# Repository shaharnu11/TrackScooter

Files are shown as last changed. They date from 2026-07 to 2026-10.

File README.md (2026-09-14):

# Apollo Track Pod — Articulated Split-Frame Suspension

Hub-motor scooter → tracked vehicle conversion. **This root is an index only — all working
files live in the per-revision folders. Every future change lands in the live revision below.**

## Live revision

**[`archive/rev012-inline-batteries/`](archive/rev012-inline-batteries/) — Rev 012, live.** The pod is
Rev 011 (below, unchanged). Rev 012 adds the scratch-built **narrow frame**: two 100×40×2 rails bolted
straight onto the rear pod's 60×6 green plates (4× M12), the two 400×110×80 batteries in line between
them, and a 6.5″ speaker firing up through the deck at each end. Bay 1226 clear, wheelbase 1706,
chassis ~21 kg. `render_mode="chassis"`; printable green-plate templates:
`rev012_green_plate_templates.pdf`.

**Pod — Rev 011** (source folder [`archive/rev011-uncut-11T-lowB/`](archive/rev011-uncut-11T-lowB/)):

No grinder: the hub rim stays factory Ø165×35, driven by a printed 11-tooth sprocket
(rib 18×16.5, wheel Ø198, cord Ø210, tooth marks every 56.6 mm on the rib). The defining
change is that the hub sits **20 mm lower** over the idler axle line (B = 150), which stops
the 1080 mm belt wasting length on its two diagonals:

| | value |
|---|---|
| Ground contact | **231.2 mm** (was 203.5 — +13.6 %) |
| Ground pressure @ ~130 kg | ~0.24 kg/cm² |
| Wheel travel | +30.7 / −29.2 mm at ±15° |
| Motion ratio | 0.4351 — the purchased springs' design point |
| Cut lengths | carrier 220 · trailing arm 184 · leading arm 166 (rear corners chamfered 10×10) |
| Guards | all PASS, zero warnings |

Folder contents: model (`apollo_track_pod_rev011.scad`), printable sprocket
(`sprocket_print.scad` + `stl/`), 2D wheel blueprint, plate cutting sheet + DXF, pod
blueprint, README, archive note.

(The first, wide box-frame Rev 012 draft stays in the Rev 011 folder as history.)

## Shared facts

Yonggu belt 1080 × 118 @ 60 pitch (pyramid-pair lugs, 22 mm centre gap) · idlers Ø108
(tread 20.27 rides *in* the lug gap) · M12 GB901 8.8 double-end stud axles + Ø15×12 sleeve
stacks (purchased) · shocks 150 mm / 100 kg-8.5 mm springs · no keel (the fork legs box the
carriers) · motor casing Ø123, hub fins 4.1 mm arching to the tunnel-floor underside.

## External documents

- **Shopping list (live, robot-maintained):** [Parts to Buy](https://docs.google.com/document/d/1putRc1Q8nmpfGutUm1MNZg5LL_oXczPzJIrjNoAym6Y/edit)
- **Drive-wheel explainer (to-scale):** https://claude.ai/code/artifact/2c1f69e1-ae04-409e-b36e-10e408f62c0e
- Older shopping docs / checklist sheet: archived in the same Drive.

## History (frozen — do not edit)

| Folder | What it was | Why superseded |
|---|---|---|
| `archive/rev010-cut-rim-10T-final/` | the grinder path: cut rim Ø149, 10T, contact 220.8 | retired 2026-08-10 — Rev 011 beats it on the factory rim |
| `archive/rev009-uncut-11T/` | Rev 011's parent: same wheel, B = 170, contact 203.5 | hub lowered in Rev 011 |
| `archive/rev008-cut-rim-9T/` | 9T max-torque wheel | excluded by the hub-fin measurement |
| `archive/rev007-cut-rim-10T/` · `rev005c/` · `rev003a/` | earlier eras | see each folder's `ARCHIVE-NOTE.txt` |

Each folder's `ARCHIVE-NOTE.txt` explains what it was and why it was superseded.

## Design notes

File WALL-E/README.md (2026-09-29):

# WALL-E

Two-track robot built on the two track pods in `../archive/`. Target: Midburn, Negev desert.

**Where we stopped:** [`PROGRESS.md`](PROGRESS.md) — read that before changing Brain, talk, or power.

- Pods: already built. This project does not modify them.
- Drive: skid steer. No steering fork.
- Control: radio remote. Autonomous safety layer on top.

## Guide

`WALLE-GUIDE.html` — whole project, one file, in build order. Open in a browser.

- 11 parts: how to use, what it is, plan, architecture, buying, frame and pods, build steps, power, firmware, safety, glossary.
- All drawings embedded. No external image files.
- PDF: open and print. One part per page break. Sheets are vector.

## Per-document pages

Every `.md` has an `.html` twin of the same name:

- `docs/00-plan.md` → [`docs/00-plan.html`](docs/00-plan.html)
- Also [`docs/BUILD.html`](docs/BUILD.html), [`docs/FRAME_AND_PODS.html`](docs/FRAME_AND_PODS.html), and the rest.
- Each page is self-contained, drawings included, and links to the others.

Guide and pages come from the same markdown, built by the same script. They cannot disagree.

## Folder

```
WALL-E/
  WALLE-GUIDE.html   whole project, one file. Generated
  build_guide.py     generates the guide and every document page
  docs/              X.md is source, X.html is generated
  cad/               model, pod interface, render script
  firmware/          Spine (Teensy 4.0), Face (ESP32-S3)
  brain/             Brain (Dell XPS 15), Python
  build/             scratch drawings. Not committed. Deletable
```

## Rebuild

```sh
cd WALL-E
cad/render_all.sh       # pod check, guards, redraw, then rebuild the guide
python3 build_guide.py  # guide and document pages only
```

`cad/render_all.sh` stops on a failed pod check or a failed guard. A clean run is proof the change is consistent.

## Pod rule

- The pods are built. **No new hole goes into a built pod.**
- Their 31 numbers exist in one file: `cad/pod_interface.scad`.
- `cad/check_pod_interface.scad` compares that file against the newest pod revision in `../archive/`.
- `cad/pod_latest.sh` selects that revision. Nothing is pinned by hand.
- MISMATCH: stop. Every dimension downstream is wrong.

2026-09-29: 31/31 agree with `rev013-double-shear` (7 new: the U braces the frame hangs from).

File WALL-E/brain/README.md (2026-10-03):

# Brain

WALL-E's laptop side: talking (mic, camera, brain, voice) and the robot
control loop. Same code on the Mac and the Windows XPS.

## Start

| What | Mac | Windows (XPS) |
|---|---|---|
| Talk, English | double-click `mac/english/start_walle.command` | double-click `windows\start_walle.bat` |
| Talk, Hebrew | double-click `mac/hebrew/start_walle.command` | `legacy\talk_hebrew.py` (old Hebrew talker) |
| Setup | [`mac/README.md`](mac/README.md) | [`windows/README.md`](windows/README.md) |

Or `.venv/bin/python talk.py --help` for every option (`--lang`, `--brain`,
`--personality`, `--mind cloud`, `--type`, ...).

## Folders

```
brain/
  talk.py            start talking (calls walle/talker.py)
  robot.py           the robot control loop (20 Hz: Spine, eyes, behaviour)
  walle/             all the code
    talker.py        the talk loops: listen, answer, barge-in, owner/visitor
    paths.py         every data folder, in one place
    lang.py          English / Hebrew lines: t(en, he)
    voice/           speech.py (Whisper + Kokoro), listen.py (speech detector),
                     echo.py (echo cancelling), loud_listen.py, util.py
    mind/            chat.py (local / cloud brains, eyes), brains.py (--brain list),
                     llama.py (llama-server), rules.py, sleeper.py
    eyes/            camera.py (faces, lips), talk_cam.py (camera window)
    people/          owner.py (Shahar's face), persons.py (people who said yes)
    modes/           management.py, personality_editor.py, tools.py (owner tools)
    music/           player.py (music folder), spotify.py
    robot/           perception.py, behavior.py, speaker_lock.py, spine_link.py, face_link.py
  rules/             how he must behave (every personality); the owner changes them in management mode
  personalities/     english/<name>/, hebrew/<name>/: who he is
  scripts/           download_models.py, spotify_sync.py, lips_test.py,
                     personality_from_video.py, download_hebrew_windows.py
  tests/             test_safety.py, test_speaker_lock.py
  experiments/       try-outs: debug_live.py, try_hebrew_voice.py, try_speaker_lock.py
  legacy/            the old Windows Hebrew talker (talk_hebrew.py, hebrew_voice.py)
  requirements/      voice.txt (talking), hebrew.txt (old Hebrew), robot.txt (control loop)
  mac/  windows/     start scripts and setup notes per computer
  models/ owner/ persons/ spotify/ music/    data (models and persons/ not in git)
```

Run every script from `brain/` (`.venv/bin/python scripts/lips_test.py`);
the owner's face enroll is `.venv/bin/python -m walle.people.owner enroll`.

## Robot control loop

XPS 15 9510. Python. Camera, personality, sounds, optional local LLM. **No internet.** Allowed to be slow and to crash. Radio is on the Spine.

Closed on the upper tray, spacers. PD 65 W+ and 12 V pack on the lower deck. USB hub on the tray (12 V rail): ELP camera, LiDAR, Teensy, Face. Speaker boxes off → tray out.

```bash
python3 -m venv .venv && . .venv/bin/activate
pip install -r requirements/robot.txt
python3 robot.py --spine /dev/ttyACM0 --face /dev/ttyUSB0 /dev/ttyUSB1
python3 tests/test_safety.py
```

Windows: `COM` ports. Sensor libs commented until hardware exists.

## Load-bearing

1. **Heartbeat is the command**, from the control loop, not a side thread. Loop stall → beat stall. Zero command is still a beat.
2. **AI never emits a motor number.** Actions: `idle` · `look_at` · `greet` · `retreat` · `nudge_forward` · `follow` · `play_sound`. `motion_for()` maps them. Cap 30 % (`tests/test_safety.py`).
3. **Stale ≠ clear.** Every reading has a time. Missing IMU blocks motion. Missing bumper halves speed.

Sensor threads write one slot. No queues.

## Still empty

IMU, LiDAR, sounds in the control loop.

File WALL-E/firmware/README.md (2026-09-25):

# Firmware

Two boards, two jobs, and a hard line between them.

| Folder | Board | Job | May it move the robot? |
|---|---|---|---|
| `spine/` | Teensy 4.0 | Motor commands, every safety rule, the watchdog | **Yes. Only this board.** |
| `face/` | ESP32-S3 × 2 | Eye animation. No servos | No |

The Brain (the Dell XPS 15) lives in `../brain/` and is Python, not firmware.

---

## The Spine

**Board:** Teensy 4.0. **Library:** `Wire` only — it ships with Teensyduino.

Build with the Arduino IDE (install Teensyduino first) or PlatformIO. Select
Teensy 4.0 and upload. There is nothing to configure at build time — every
tunable number is in `spine/config.h`.

> No data bus. Analogue throttle. `FlexCAN_T4` is gone.

### What it does

One loop at 1 kHz. Every pass it rebuilds the motor commands from scratch using
the fixed rule order in `../docs/01-architecture.md` section 3. The rules are in
`arbitrate()` in the same order as the document, with the rule numbers in the
comments, so the two can be checked against each other.

### How it drives a scooter controller

A scooter controller takes a **throttle voltage** and tells you nothing back.
So the Spine does all of this itself:

| What | How |
|---|---|
| Speed | MCP4725 DAC per side, through a level shifter (the Teensy is **not** 5 V tolerant) |
| Direction | a separate opto-isolated **reverse** line per side |
| Stopping hard | an opto-isolated **e-brake** line per side, the same input the E-stop uses |
| Pack voltage (rules 5, 11) | a resistor divider per pack into an analogue pin |
| Motor temperature (rule 9) | each hub motor's **own thermistor** |
| Is the track alive? (rule 4) | counting that motor's **hall edges** |
| Motor current | ACS758 per pack — telemetry only, no rule depends on it |

### Pins

| Pin | Use |
|---|---|
| 0, 1 | Serial1 — iBus from the RC receiver |
| 2 | Arm output → contactor coil MOSFET. LOW = contactors drop |
| 3 | E-stop sense, active LOW |
| 4 | ToF ring reset |
| **5** | **Watchdog kick — see below** |
| 6, 7 | Reverse line, left / right |
| 8, 9 | E-brake line, left / right |
| 10, 11 | Hall input, left / right |
| 13 | On-board LED heartbeat |
| 18, 19 | I2C — the two DACs and the ToF multiplexer |
| A0, A1 | Pack voltage divider, left / right |
| A2, A3 | ACS758 current, left / right |
| A6, A7 | Motor thermistor, left / right |

### The watchdog is the most important wire on the robot

**A scooter controller never releases the motor on its own**, and the DAC holds
its last voltage forever. So if this board
crashes mid-drive, the robot keeps going at whatever throttle it had.

The only thing that stops it is the hardware watchdog: pin 5 square-waves while
the firmware is healthy, holding a **normally-closed** relay open. Stop the
pulses and the relay falls closed and shorts both throttle lines to ground.
Nothing in software has to work for that to happen.

`wdt_kick()` refuses to kick when the last DAC write failed. That is not a bug
and it is not optional — see the gotchas at the bottom.

### Before you flash it to a robot that can move

Read the five rules at the top of `spine/spine.ino`. The short version: no
dynamic memory, nothing that blocks, nothing with unbounded runtime, every new
failure path ramps to zero, and features belong on the Brain.

Then **measure your own throttle** and put the numbers in `config.h`:
`THROTTLE_REST_V` and `THROTTLE_FULL_V`. Read the scooter throttle's signal
wire at rest and at full with a multimeter. The defaults (0.80 V and 4.20 V)
are typical, not yours. Get them wrong and the robot either creeps when it
should be stopped, or never reaches full speed.

Calibrate `VOLT_SCALE_L` and `VOLT_SCALE_R` the same way: multimeter on the
pack, compare with the telemetry line, correct until they agree. Rule 11
divides by that number.

### Still to do

`tof_poll()` is empty. The bumper ring is not implemented yet.

This is deliberately failing in the safe direction: with no valid sensor
readings, `bumper_scale()` returns 0.5 and halves the speed. **Do not make it
return 1.0 to get full speed for a test.** That silently switches off the veto,
and it is exactly the kind of temporary change that stays in.

### Testing it without a robot

The Brain link is plain text, so you can drive the board from a serial
terminal at 115200:

```
C 0.2 0.0 1
```

means "20 % forward, no turn, sequence 1". Send one every 50 ms or the
watchdog will stop obeying you, which is itself a good first test. The board
prints a status line 20 times a second, including why it is not moving:

```
S 12345 manual running duty 0.200 0.200 v 49.8 49.6 t 31 30 i 2.1 2.0 hall 8123 8110 rc 1 brain 1 dac 1
```

`dac 1` means this board still controls the throttle. If it ever reads `0`, the
hardware watchdog should already have stopped the robot.

The tests that matter for this firmware are in `../docs/03-safety-log.md`:
**8** (throttle wire pulled — both tracks must stop), **15** (Spine unpowered),
**16** (Teensy alive but I2C dead), and **17** (reverse line glitch).

---

## The Face

**Board:** ESP32-S3, two of them, one per eye. **Libraries:** LovyanGFX.

### Same binary on both boards

Tie `PIN_EYE_SELECT` to ground on the left board and leave it floating on the
right. The firmware works out which eye it is at boot. There is only ever one
binary to keep track of, and swapping in a spare board in the field needs no
laptop.

### Why two boards and not one

The 480×480 round panels are QSPI and need real bandwidth. One ESP32-S3 can
*probably* drive two, and would then tear the moment you add anything else.
Two boards at 12 dollars each removes the risk and means one eye keeps working
if the other board dies. `../docs/05-bom.md` section 4.

The two are kept in step by a single wire: the left board pulses it, the right
board starts its frame on the pulse. If that wire breaks, each eye runs on its
own clock and the only symptom is that the blinks drift apart slightly.

### Still to do

`face/panel_cfg.h` is a placeholder. The QSPI panel's init sequence and pin
mapping have to be copied from the vendor's example for the exact module you
buy — it is the one part of this project that cannot be worked out from first
principles.

Everything else runs without it. You can develop and test the whole animation
over the serial link with no screen attached, which is worth doing because the
animation is the hard part.

### Testing it

Three commands, typed by hand at 115200:

```
GAZE -20 5
MOOD curious
BLINK
```

Moods: `idle`, `curious`, `happy`, `sad`, `alarm`, `sleepy`.

If the link goes quiet for 1.5 seconds the eyes fall back to an idle
behaviour — drifting around, blinking now and then. That is on purpose: a
crashed Brain should leave a robot that looks bored, not one that looks
broken. Frozen eyes read as "switched off" to everyone watching.

---

## The three details in here that are easy to get wrong

**The slew limiter's direction.** In `spine.ino`, `slew1()` treats "up" as away
from zero and "down" as towards zero. Swap them and stopping becomes slower
than starting, which is the wrong way round and would not be obvious from
watching the robot drive.

**`wdt_kick()` must stay gated on `output_ok`.** It looks like a bug — the
board is alive, so why not kick the watchdog? Because the watchdog's job is to
stop the robot when the **throttle** is out of control, not when the CPU is.
A Teensy that is running fine but has lost the I2C bus to a DAC would otherwise
keep kicking happily while the throttle stayed stuck at its last value. That
blind spot is closed by refusing to kick. Safety log test 16.

**The reverse line is never flipped while the wheel is turning.** `side_out()`
commands zero and waits for the halls to fall silent first. Scooter controllers
commonly refuse to change direction under motion, and some are damaged by being
asked. Removing that interlock would make direction changes feel snappier on
the bench and would eventually break a controller. Safety log test 17.

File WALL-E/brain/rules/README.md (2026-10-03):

# WALL-E's rules

How he must behave, in every personality. Read at start-up and added to his
instructions **after** the personality, which is told: if anything in it
conflicts with these rules, the rules win.

- The owner changes them by voice in management mode ("answers can be up to
  three sentences"): read back, saved on "yes", the old file in `history/`.
  Or by hand.
- These are soft rules, instructions to the brain: it almost always follows
  them. The hard rules live only in code and cannot be changed by voice: sentence limit, filters
  (walle/mind/chat.py), owner/visitor checks and tools (walle/talker.py,
  walle/modes/), consent (walle/people/persons.py).
- `<!-- comments -->` and `#` headings are not sent to the brain.

| File | When |
|---|---|
| always.md | always |
| english.md / hebrew.md | by --lang |
| eyes_picture.md | the brain sees camera pictures (Qwen3-VL) |
| eyes_described.md | the brain gets the picture as words (Hebrew: DictaLM + eyes) |
| eyes_none.md | no camera pictures |

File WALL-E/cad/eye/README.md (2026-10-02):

# WALL-E eyes — steel tube + printed cartridge

Decided with Shahar, 2026-10-01. One eye = one steel tube + one cartridge.

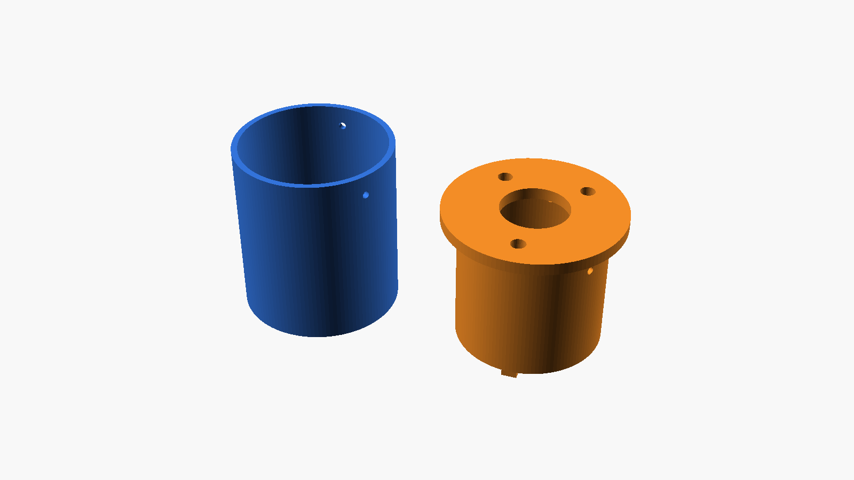
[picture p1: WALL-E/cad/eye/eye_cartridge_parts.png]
the 2 printed parts


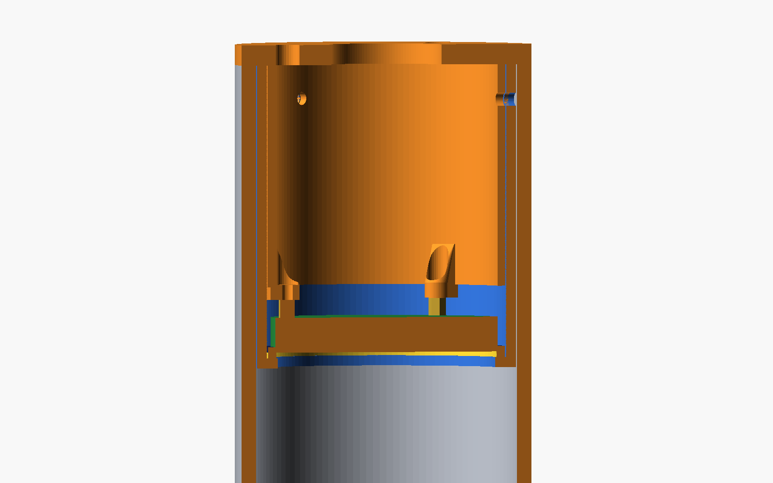
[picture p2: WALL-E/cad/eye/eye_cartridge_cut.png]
assembled, cut in half


## Decisions

- **Tube:** steel, **54 mm inside × 90 mm long** (owner's). Outside Ø: **measure**.
- **Screen + computer:** Waveshare **ESP32-S3-Touch-AMOLED-1.75**: round AMOLED
  466×466, 700 nits, ESP32-S3R8 on the back. Touch not used.
  - Bought: 2 × standard + 1 × **-G** (GPS version). The GPS board is one eye
    and the GPS. One standard board is the spare.
- **Sun shade:** glass front sits **33 mm deep**. Paint the inside of the tube
  **matte black**.
- **Mount:** 2 printed parts. The board screws onto part 2 with **3 × M2**
  into its own brass posts. The eye is built on the table, then slides into the
  tube. **3 × M3** from outside hold it.
- **Wires:** the USB-C is on the board edge, facing the tube wall: no room for a
  plug. Use the **header on the back** instead (see Wiring).
- **AMOLED burns in:** the eyes must always move a little, and turn off in sleep.

## Board numbers (Waveshare 3D model)

Measured from the glass front, along the axis:

| What | Size / depth |
|---|---|
| Glass | Ø48.96, 1.10 thick |
| Picture (visible) | Ø44.16 |
| Board | Ø46.0 |
| USB-C (edge, r 23.8) | ends 10.15 behind the glass |
| 3 brass posts, M2, Ø3.5 | tips 10.43 behind the glass; at (±13.75, 14.70) and (0, −20.50), header side up |
| Header (female, 8 pins) | ends 12.70 behind the glass |

## Parts per eye

| # | Part | Size | Source |
|---|---|---|---|
| 1 | Steel tube | 54 inside × 90 | owned |
| 2 | Matte black paint inside, front ~35 mm | steel primer + flat black | local |
| 3 | **Part 1** (`eye_part1.stl`): sleeve + front lip | outside 53.6, inside 49.5, lip hole 45, 60 long | print |
| 4 | Foam ring | outside 49, hole 45.5, ~1.5 mm | cut from closed-cell (EPDM) foam sheet |
| 5 | Eye board | Waveshare AMOLED 1.75 | bought |
| 6 | **Part 2** (`eye_part2.stl`): carrier tube + cap | outside 49.1, cap Ø = tube outside | print |
| 7 | 3 × **M2×6** screw | board posts → part 2 | local / AliExpress |
| 8 | 3 × **M3** self-tapping screw, ~8 mm | steel + part 1 + part 2 | local |
| 9 | **PG16** cable gland, black | in the cap, hole 22.8 | AliExpress |
| 10 | Silicone sealant | gland + the 3 screwdriver holes in the cap | local |
| 11 | 4 wires: Dupont male → header; 4-core shielded 24 AWG | VBUS, GND, TXD, RXD | AliExpress |
| GPS eye only | IPEX → SMA pigtail 20 cm, SMA extension 50 cm, QUESCAN antenna | antenna under the head top cover | bought |

## Print

- **PETG or ASA, black.** Not PLA (soft at ~55 °C; steel in the sun gets hotter).
- 4+ walls, 40 % infill (the screws go into it). No supports.
- Part 1: lip down. Part 2: the STL is already cap down.
- Print **3 sets** (2 eyes + 1 spare).
- Re-export after a change:
  ```
  openscad -D part=\"p1\" -o eye_part1.stl eye_cartridge.scad
  openscad -D part=\"p2\" -o eye_part2.stl eye_cartridge.scad
  ```

## Assembly (per eye)

1. GPS board only: unplug the small antenna (IPEX plug next to the USB-C, lift
   straight up), unscrew it. Plug the pigtail into the same socket.
2. Program the board once on the table, with a normal USB-C cable.
3. Plug the 4 wires into the header (male Dupont). Drop of hot glue on them.
4. Wires (and the pigtail) through the PG16 gland in the part 2 cap.
5. Board onto the 3 pads of part 2. **3 × M2×6** through the 3 screwdriver holes
   in the cap. Do not overtighten: the posts are small.
6. Stick the foam ring on the back of the part 1 lip.
7. Part 2 (with the board) into part 1, glass first, until the glass touches the foam.
8. Whole cartridge into the painted tube from the back, until the cap sits on the tube end.
9. Drill 3 × 3.2 mm through the steel at the 3 holes (7 mm from the end).
   Drive 3 × M3 self-tapping screws.
10. Tighten the gland. Seal the gland and the 3 screwdriver holes with silicone.

**Repair:** cut the silicone, remove 3 × M3, pull the cartridge out.

## Wiring

Header on the back: `IO18 · IO17 · IO16 · RXD · TXD · 3V3 · GND · VBUS`

| Eye pin | Goes to |
|---|---|
| VBUS | +5 V from the RCNUN 12→5 V converter |
| GND | GND (converter and CP2102) |
| TXD | CP2102 **RXD** |
| RXD | CP2102 **TXD** |

- The CP2102 plugs into the USB hub. Leave its +5V and 3V3 pins empty.
- GPS board: IO17 / IO18 belong to the GPS. Do not use them. The eye firmware
  forwards the GPS data on TXD/RXD.

## Files

| File | What |
|---|---|
| `eye_cartridge.scad` | the 2 parts. `part = "p1" / "p2" / "all" / "cut"` |
| `eye_part1.stl`, `eye_part2.stl` | ready to print |
| `eye_cartridge_parts.png` | the 2 parts |
| `eye_cartridge_cut.png` | assembled, cut in half |

## Still open

- Tube **outside Ø** → set `tube_od` (now 60, a guess) and re-export part 2.
  It only changes the cap's outer edge. Part 2 works as it is.
- Check the real board when it arrives (post positions, header height), before
  printing all 3 sets. Print 1 set first.
- Firmware: `firmware/face` is written for the old 2.1" screen. The new board uses
  a CO5300 driver (QSPI). Start from Waveshare's example code for this board.
- `cad/walle_frame.scad` and `docs/02-overview.md` still describe the old eye
  (Ø99 barrel, 60 mm recess, acrylic dome).

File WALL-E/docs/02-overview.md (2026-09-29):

# 02 — What this robot is

Two-track robot on the pods in `../archive/`. Midburn, Negev. Pods are built. This project does not modify them.

- Pods **side by side**. Skid steer. No steering fork.
- Box on top: batteries, three computers, two speakers.
- Rigid head. Two screens as eyes.

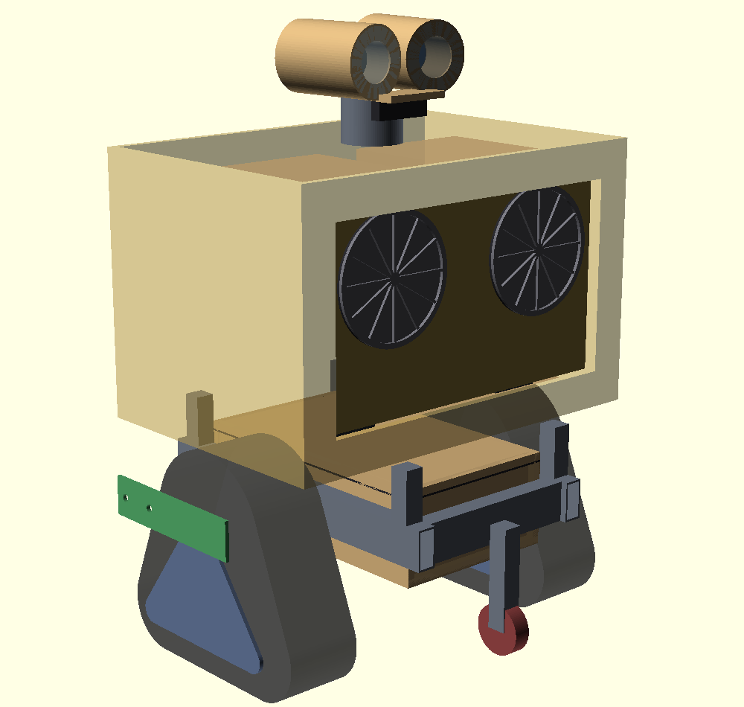
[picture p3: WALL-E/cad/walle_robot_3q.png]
The robot, three quarter view


## Control

- A person drives with a radio. **Not self-driving.**
- Safety: sensors veto obstacles, including against the stick.
- Personality: camera finds faces, eyes follow, body turns (head is rigid), sounds play.

## Three computers

| Name | Board | Job | Timing |
|---|---|---|---|
| Brain | XPS 15 9510 (owned) | Camera, local LLM, sounds | 0.1–3 s OK |
| Spine | Teensy 4.0 | Radio, motors, stop rules | 1 kHz |
| Face | ESP32-S3 × 2 | Two eye screens. No servos | 30 Hz |

- No internet. Radio and E-stop into the Spine.
- Brain crash: eyes and sound die. Driver keeps control.

## Numbers

Body narrower than the tracks on purpose.

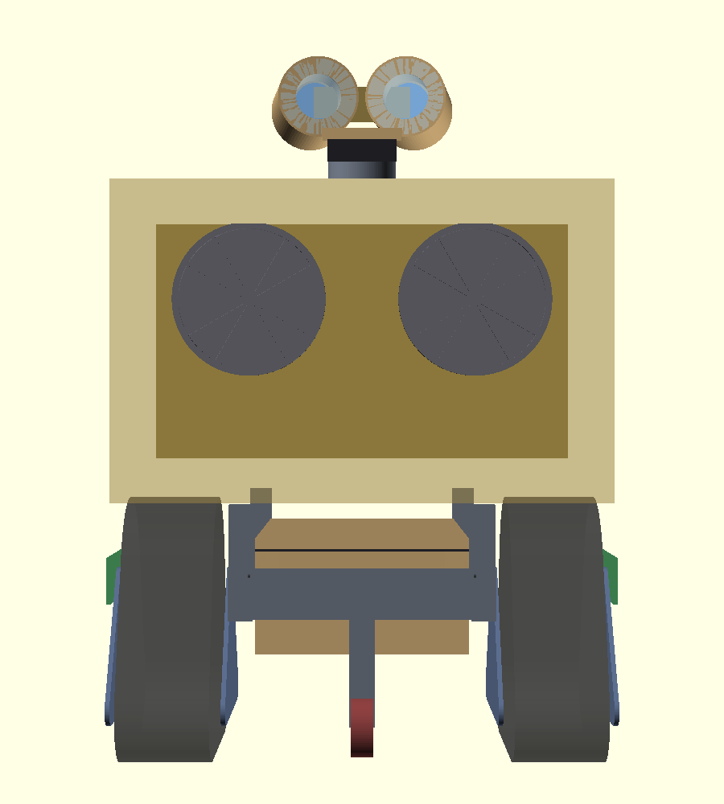
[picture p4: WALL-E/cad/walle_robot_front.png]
From the front


| | |
|---|---|
| Width | 677 mm (pod centres 500) |
| Height | 1003 mm to barrel tops |
| Body | 430 × 640 × 400, floor 428 mm |
| Rails | 60×30×3, 550 long, 251 mm clear |
| Lowest point | 150 mm (box floor) |
| Mass | 94.9 kg — pods/packs/electronics still guesses |
| CoM | 355.5 mm up, 4.5 mm forward |
| Tips forward | 17.4° (back 18.7°) |
| Castor catches | 12.3° — **5.1°** margin |
| Ground pressure | 0.174 kg/cm² |

The frame hangs from the pods' U braces. Pod off: 1 × M12 + 4 × M10 per side. Weigh a pod and a pack before trusting 17.4°.

## Model results

1. **No electronics in the frame.** 8 mm above packs, 24 mm between. Two floors in the body. 12 V pack 181 × 167 × 77 mm on the lower deck (not the 400 × 110 × 80 mm traction case). Upper: 315 × 360 mm tray for closed XPS + USB hub. Speaker boxes off, then tray out.

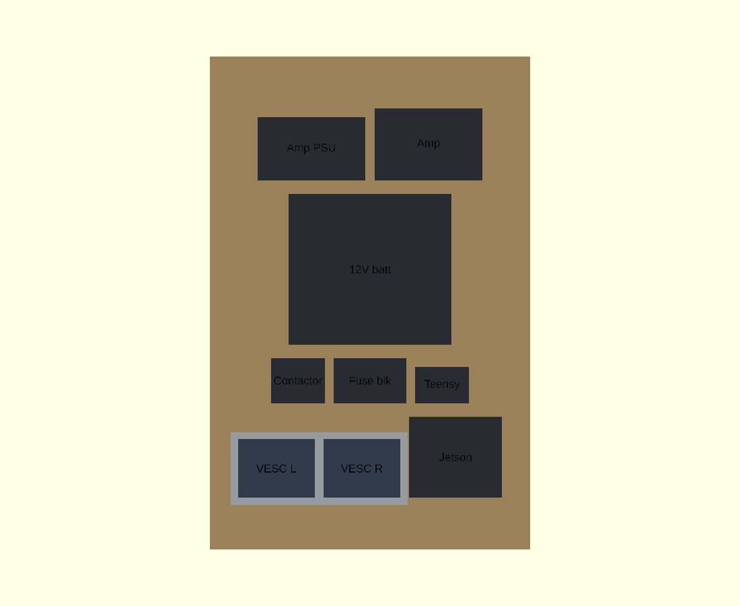
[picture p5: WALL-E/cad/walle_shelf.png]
The electronics shelf, labelled


2. **Body floor clears the U brace tabs** (413 mm + M10 heads), not the belt crown (327 mm) or the frame (252 mm). Four 176 mm risers.

3. **Battery box closed.** Six panels, gasket, plugs, vent. Daily charge in place. Packs still lift out (L17).

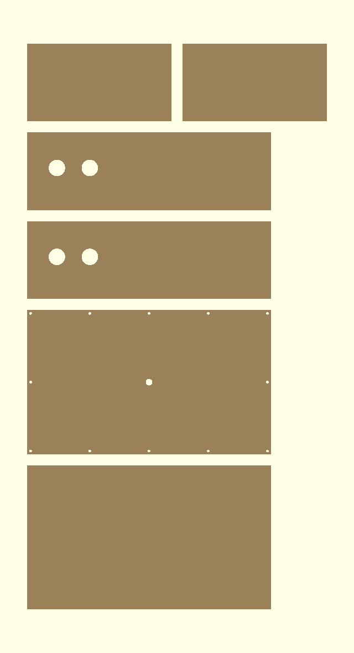
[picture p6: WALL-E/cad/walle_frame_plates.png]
The plywood cutting layout


4. **Chest is a 12 mm plate**, set back 20 mm. Speaker baffle.

## Speakers

- 2 × 6.5 inch, 330 mm apart, 613 mm up. On the chest edges. 140 mm between rims.
- 7 inch LCD, 107 × 183 mm, **portrait**, between them. HDMI from the XPS. Glass window 90 × 160. Bezel on the chest, not through the speaker boxes.
- 7.5 L sealed box each. Bolt on. Shade 54 % of the shelf.
- 6.8 kg, both forward. Castor margin now 5.1° (the U-brace mount lifted the body). Weigh before adding high/forward mass.

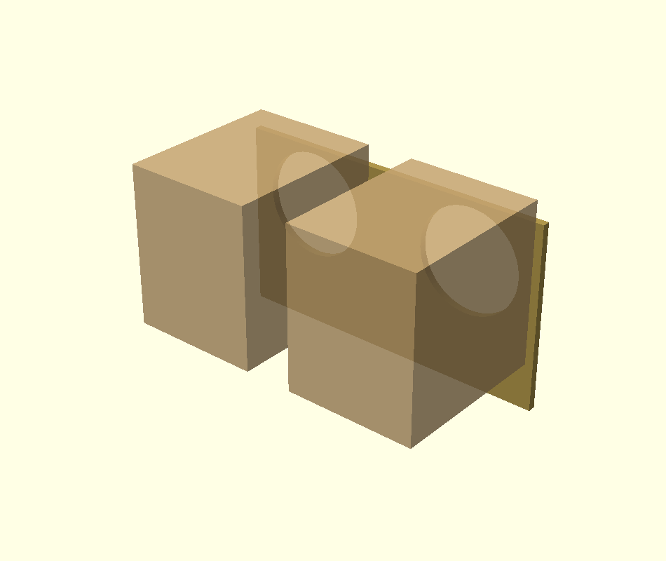
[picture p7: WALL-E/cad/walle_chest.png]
The chest panel and the two sealed enclosures, from behind


## Head

- Barrels Ø105, 128 mm apart, toe 6°.
- 2.1 inch screens, 60 mm recess, clear dome. Shade above 49° sun. Midday 75–80°.

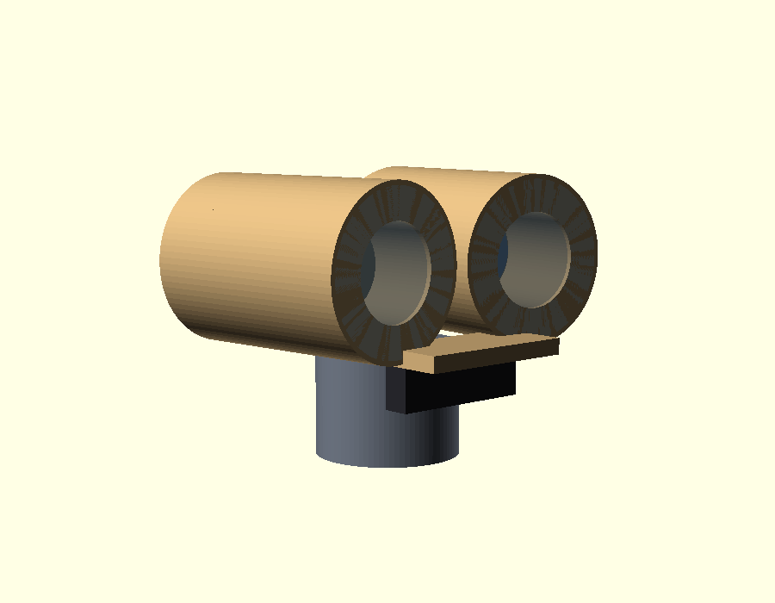
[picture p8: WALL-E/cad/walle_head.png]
The head, with the two eye barrels


Camera under the brow: ELP cube 42 × 42 × 36 mm, 86°.

## Built pods (rev013)

| | |
|---|---|
| Mounting width | **177 mm** over carriers (plates 165 mm) |
| Contact | 231 × 118 mm |
| Pod | 363 × 327 × 177 mm |
| Band | 60 mm, 197–257 mm up |
| Travel | +30.7 / −29.2 mm |

`../archive/rev013-double-shear/`. Tape-measure before welding.

## Open

1. D4 — pack Ah and BMS. Equal traction packs.
2. D3 — carry a person? Midburn rules before weld.
3. D6 — anti-tip. 231 mm is the whole footprint.

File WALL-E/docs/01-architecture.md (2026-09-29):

# 01 — Architecture

Three boards. The rules that decide who may move the robot.

## 1. Why three boards

| Job | Must react in | If late |
|---|---|---|
| Stop the motors | 1 ms | Someone gets hurt |
| Animate the eyes | 30 ms | Face looks broken |
| Read a camera frame | 100 ms | Nobody notices |
| Pick a line of speech | 3 s | Fine |

Linux can pause for seconds. A 200 kg machine must not. Motor commands live on a board with **no OS**.

## 2. Layout

```
RADIO ──2.4 GHz──► RC RECEIVER ──iBus──► SPINE (Teensy 4.0)
                                         ▲
LiDAR, ELP cam, GPS, mic ──► BRAIN (XPS) ┤ USB 20 Hz heartbeat
                         local, no net   │ HDMI ──────────► CHEST 7 inch LCD (portrait)
                         USB serial ─────► FACE (ESP32-S3 × 2, screens, no servos)

ToF ring ──► SPINE ──I2C──► 2× MCP4725 DAC ──opto──► 2× scooter controller ──► hub motors
E-stop  ──► SPINE           hardware watchdog shorts both throttles if kicks stop
```

- Radio and bumpers wire into the **Spine**, not the Brain.
- Brain crash costs eyes and sound. Driver keeps the sticks.

## 3. Spine loop (1 kHz)

Higher number loses. Every pass rebuilds motor commands from scratch.

| # | Check | If it fails |
|---|---|---|
| 1 | E-stop closed? | Motors dead. Physical. No override |
| 2 | Arm switch ON? | Send zero |
| 3 | Radio frame in last 100 ms? | Ramp to zero |
| 4 | Each track turning as commanded? (hall edges) | Ramp **both** to zero |
| 5 | Both pack voltages above the floor? (dividers) | Ramp **both** to zero |
| 6 | Mode switch | MANUAL = sticks. ASSIST = Brain may request |
| 7 | ASSIST only: Brain heartbeat in last 100 ms? | Ramp to zero, fall to MANUAL |
| 8 | Bumper close in the direction of travel? | Scale down or to zero. Veto only |
| 9 | Motor too hot? (hub thermistor) | Scale both down |
| 10 | Slew limit | Smooth ramp |
| 11 | Scale each side by its own pack voltage | Straight drive as packs drift |
| 12 | Write DACs. Kick watchdog | Stop kicking if a DAC write fails |

Every failure stops the robot. Nothing speeds it up or ignores the driver.

Controllers report **nothing**. So:

- Rule 4 = hall edges. Commanded to move, halls still: track is dead.
- Rules 5 and 11 = resistor divider per pack.
- Rule 9 = motor’s own thermistor.

A scooter controller has **no command timeout**. A DAC **holds its last voltage**. If the Teensy dies while packs are alive, only the **hardware watchdog** (NC relay shorts throttle to ground) stops the robot. Safety log tests 15 and 16.

## 3b. One pack per pod

Positives never meet. Negatives bonded at **one** point, including the 12 V pack negative. Do not fuse the bond.

**Trap 1 — crooked drive.** Same duty on 50 V vs 44 V is a pull. Rule 11 scales by pack voltage.

**Trap 2 — one dead side pivots the robot.** BMS cut is the usual cause. Rules 4 and 5 stop **both** tracks.

**Trap 3 — floating ground.** Far-pack readings look real and are wrong. One bond, three negatives, two positives that never meet. Bond sized for 40 A. Not fused.

**D8.** Electronics: 12 V 20 Ah, 181 × 167 × 77 mm, on its side, lower deck. Traction packs equal (~17.5 Ah). Drive ~5.6 h. Electronics ~12 h.

| What dies | What stops the robot |
|---|---|
| Pack A | Coils lose 48 V. Both contactors open. Copper |
| 12 V pack | Teensy dies. Arm MOSFET opens the coil chain |
| Pack B | Only rule 4 (halls). Contactor B stays closed with no power behind it |
| Teensy crash, packs alive | Watchdog only |

Coils stay on pack A. Amp stays on 48→24 V off pack A. Do not move either onto 12 V.

## 4. Brain heartbeat

Brain sends speed, turn, and a counter every 50 ms.

- Last message < 100 ms: continue.
- Else: Brain dead. Ramp to zero in 0.5 s (do not slam — 231 mm footprint can tip). Ignore Brain until messages return for 1 s.

In MANUAL a dead Brain does not stop the robot. Sticks go straight into the Spine.

## 5. What each board runs

**Brain — XPS 15 9510, Python, no internet.** Closed on the upper tray (L26). PD pack 65 W+ on the lower deck.

- Occupancy from LiDAR (geometry, not AI).
- ELP-USB1080P03-KLC1100, 86°. YuNet faces on **CPU**. Mouth motion. Speaker-lock. Distance from face size. ToF ring for close range.
- Chest 7 inch HDMI, portrait, between the speakers. Status and captions. Not motors.
- Personality picks `idle` · `look_at` · `greet` · `retreat` · `play_sound` · `nudge_forward`. Optional local LLM (3B, 4-bit) only from that list. **Never a motor number.**
- Log temperatures, voltages, vetoes.

**Spine — Teensy 4.0, C++, no OS.** Section 3 only. Reads thermistors, dividers, ACS758, halls. Forwards telemetry.

**Face — ESP32-S3 × 2.** `GAZE` / `MOOD` → pupils and blinks. No servos.

### Look = drive

Head is rigid. Camera FOV **is** robot FOV: **86°** (±43°). Blind until the body turns. Full own-path width from **363 mm** ahead. Closer: ToF ring.

A look-turn is a normal drive command. Same slew, current, tilt, bumper, watchdog, plus:

| | Rule |
|---|---|
| L1 | Brain requests a **heading offset with a timeout**, never raw motors |
| L2 | Look-turn rate is a fraction of drive turn |
| L3 | Any stick input cancels the look. RC ch 6 = look-turn enable |

Pivot on sand is the peak current. Test ACS758 on a turn in place, not a straight line. Prefer a gentle arc.

## 6. Modes

- **MANUAL** — sticks. Bumper and temp still apply. Brain is cosmetic. Use this in a crowd.
- **ASSIST** — Brain may request a slow turn. Stick above deadband wins for 2 s.

Build MANUAL first.

## 7. Build order

| Stage | Test |
|---|---|
| 1 | One motor, hand throttle, no Teensy. Spins |
| 2 | Teensy → one DAC. Number moves the motor |
| 3 | Radio. Stick moves it. TX off stops it |
| 4 | **Watchdog before the second track.** Kill Teensy power: motor stops |
| 5 | Second controller, mixing, on blocks |
| 6 | E-stop and arm. Cause every §3 failure |
| 7 | First sand drive, no body, tethered E-stop. Watch current on a pivot |
| 8 | Bumpers. Refuses a cardboard box |
| 9 | Face, Brain idle. Eyes follow a hand |
| 10 | Camera + personality. Pupils follow a person. Head still |
| 11 | Look-turns on ch 6. Stick cancels |
| 12 | Body and sound |

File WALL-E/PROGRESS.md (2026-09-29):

# WALL-E — where we stopped

Read this first. Date: **2026-09-26**. Branch: `walle-xps-two-floor-packs`.

This is the Midburn tracked robot that uses the two Apollo pods. The original scooter is a separate machine. Do not mix their wiring rules.

Talk to the owner in short numbered points and everyday English. Do not commit unless asked. Do not push unless asked. Do not skip contactors. Do not treat garden autonomy as Midburn self-drive.

---

## What works right now (Mac, tonight)

Hebrew talk with the USB camera is **live and answering**.

```bash
cd WALL-E/brain
PYTHONUNBUFFERED=1 ./.venv/bin/python -u talk_hebrew.py --auto
```

- Window title: **WALL-E speaker lock**. Green **YOU** box = talker. `q` quits.
- No Enter. Face lock + loud mic (`rms > 0.025`) starts a recording. Mouth motion stays near 0 on this camera, so sound is the gate on purpose. Music with a visible face can still trigger a listen.
- Pipeline: ivrit Whisper Large v3 (CPU int8) → DictaLM 1.7B MLX 8-bit → BlueTTS.
- Models live in `brain/models/` and are **not in git**. Download: `python3 download_hebrew_voice.py`.
- Venv: `WALL-E/brain/.venv` (Python 3.14). Homebrew `python3` has no `cv2`.
- It is **slow**. Whisper on CPU is the wait. Chat on this Mac already uses Apple GPU via MLX. XPS later: Whisper on CUDA; MLX will not run (need GGUF/CUDA). XPS 15 9510 GPU is about 4 GB — Whisper + chat may not both fit.

Debug camera+mic only (no LLM):

```bash
PYTHONUNBUFFERED=1 ./.venv/bin/python -u debug_live.py
```

Known bugs still in the live loop:

1. Mouth motion (`mouth_ema`) stays ~0. Listen uses **sound**, not mouth.
2. YuNet false faces (plants). Mitigated: `max_faces=1`, score 0.55, `min_rel_h=0.08`. Sit close.
3. He can hear his own speaker after TTS. No mute-while-speaking yet.
4. `TalkCam.locked()` was missing; added. Do not rename it to `.lock` — that is the `SpeakerLock` object.

---

## Brain map

| File | Role |
|---|---|
| `brain/personality.py` | Named actions only. **Never a motor number.** |
| `brain/talk_hebrew.py` | Live Hebrew + camera lock |
| `brain/usb_camera.py` | ELP, YuNet, mouth EMA |
| `brain/hebrew_voice.py` | Whisper + BlueTTS |
| `brain/speaker_lock.py` | Who is talking |
| `brain/perception.py` | Snapshot. `tof_poll()` still empty |
| `brain/main.py` | 20 Hz loop to Spine (not wired to talk yet) |
| `brain/test_safety.py` | Personality invariants |

Garden ASSIST (radio **on**, sticks centred, Spine still owns stop):

- Close person `< 1.2 m` → `retreat`
- No person + `may_move` → 25% chance `nudge_forward` (1 s, 0.25)
- Person 1.5–4 m + `may_move` → `follow` (speed 0.20, turn from `gaze_az`, clamp ±0.20)

**Owner said: build follow later.** Code is already in `personality.py`. Do not push more follow until asked. Midburn stays MANUAL / radio. No unsupervised crowd self-drive.

---

## Locked hardware / safety (do not reopen)

- Teensy owns motors. Radio and E-stop on the Spine.
- Brain = owned XPS 15 9510. Offline. No Jetson. No cloud at the event.
- Pack A+ and Pack B+ never meet. Contactor coils on Pack A.
- 12 V electronics pack (D8). XPS not on that rail. Every battery removable.
- Head rigid. Gaze = pupils. Camera = ELP-USB1080P03-KLC1100.
- **DC contactors stay.** Owner asked to skip them more than once. Refuse.
- Low-level e-brake = pull to GND via PC817. Radio stays on in ASSIST.
- The frame **hangs from both pods' U braces** (2026-09-29). Per pod: a 60×6 hanger on the inboard carrier face, on the U brace's inboard M12 (now M12×40), and a tab clamped to the U bridge by 4 × M10 beside the bridge. No new hole in a pod. The green plates are not used (only the rear pod has them).
- CAD frame is still **60×30** unless the owner asks to change it to 100×40.

---

## Contactor / fuse buy (decided in chat; **BOM and wiring doc updated 2026-09-29**)

Now in `05-bom.md` and `04-power-and-wiring.md`: ZJ50A, 30 A fuse (10×38 gPV, changed from 40 A on 2026-09-29), XT60, three wire sizes (12 / 16 / 22 shielded). Decision:

| Item | Decision |
|---|---|
| Contactor | **ZJ50A** (or ZJ100A), **48 V coil**, 1NO, **DC** rated. Not CJX2-K (that listing is coil-only / AC). |
| Fuse | **30 A** 10×38 gPV 1000 V DC (was 40 A; owner 2026-09-29), **smaller than the contactor**. Anything on 48 V must be **≥ 58 V DC**; blade and J-case are 32 V. |
| Main plug | Owner already has **XT60**. Allowed for ~250 W **only if you plug with contactors open**. |
| Mushroom | **NC on the coil chain only** (~0.3 A/coil). Battery motor current does **not** go through the mushroom. |
| Arm | Radio channel 3. Coil powered while armed. |

Do not “limit amps in software” instead of contactors. Nameplate 250 W / 48 V is not stall current.

Lighting buy (WS2815 12 V 60/m IP67, fused 12 V, not 48 V) was designed in chat. **Not in the BOM yet.**

---

## Still open / next work

1. Mute the mic while TTS plays (he talks to himself).
2. Port talk to XPS: CUDA Whisper, non-MLX chat, keep answers short.
3. Wire `talk_hebrew` into `main.py` / personality (one place for camera + rules + talk).
4. Follow behaviour: already coded; owner wants it later.
5. ~~Update BOM/docs to ZJ50A + fuse + XT60~~ — done 2026-09-29 (30 A fuse). WALLE-GUIDE.html still needs a rebuild on the Mac (`cad/render_all.sh`, then `build_guide.py`).
6. CAD 100×40 only if asked.
   **Done 2026-09-29: the frame hangs from the U braces** (`cad/walle_frame.scad`, `docs/FRAME_AND_PODS.md` section 3). Cost: body floor 335 → 428 mm, robot 910 → 1003 mm, forward tip 18.9° → 17.4° (castor still catches first at 12.3°). Owner accepted the height. Owner says both built U braces are the same height; the model uses 407 mm for both. **Measure both bridge tops** before cutting the hangers.
7. `tof_poll()` empty. IMU/LiDAR empty.
8. Do not commit `brain/models/` weights.

Hebrew character = SYSTEM prompt in `talk_hebrew.py`, not a fine-tune.

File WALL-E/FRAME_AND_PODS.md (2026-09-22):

# Frame and pods — the mechanical facts, in one place

This is the page to read before you cut, drill, or weld anything. It answers
one question: **where does the frame meet the pods, and what is allowed to
change?** The step-by-step build order is in [BUILD.md](BUILD.md), further down
this same guide page.

---

## 1. The rule that comes before everything

The two track pods are **built**. Nothing in the WALL-E project changes them.
**No new hole goes into a built pod.** The frame is designed around what the
pods already are, never the other way round.

Because of that rule, the pod numbers are not typed into the frame model. They
live in one file, `pod_interface.scad`, and a checker compares that file against
the real pod model:

```
cd WALL-E
./pod_latest.sh                                        # point at the newest revision
openscad -o chk.echo --export-format echo check_pod_interface.scad
```

`pod_latest.sh` picks the **highest** `archive/revNNN-*/apollo_track_pod_revNNN.scad`
on disk and writes `pod_latest.scad`. So WALL-E always follows the latest pod
revision. Nothing is pinned to an old one by hand. `render_all.sh` runs this
first and **stops** if the check says MISMATCH, because every dimension
downstream of a wrong pod number is also wrong.

Today the newest revision is **rev013-double-shear**, and all 23 numbers agree.

---

## 2. The z stack — what the rail actually touches

Measured on the built pods (2026-09-18), outward from one pod's centre plane:

| From | To | What |
|---|---|---|
| 0 | 59 | belt, 118 wide |
| 76.5 | 82.5 | **green plate**, 60×6 — the two M12 holes are in here |
| 82.5 | 88.5 | **carrier plate**, 40×6 |
| 88.5 | 92.5 | scooter fork leg — **not fitted on WALL-E** |

**This order changed.** In rev012 the green plate was the outermost part and the
rail bolted flat onto it. Rev013 measured the real pods: the plate is **inboard**
of the carrier, so the carrier now stands **6 mm proud** of the plate.

Consequence, and it is the whole reason this page exists:

- The rail comes in from the middle of the robot and **lands on the carrier**,
  at 88.5 from the pod centre. That is `pod_mount_z`.
- The M12 holes are 6 mm further out, in the green plate.
- So the bolts cross a **6 mm air gap**, and that gap needs a **packer**.

The carrier cannot be dodged: it is only 40 mm wide (±20 either side of the hub
axle) but it runs the full height of the 197–257 mm rail band.

---

## 3. The joint, part by part

Per side, inboard to outboard:

```
M12 head  →  rail inner wall  →  Ø25/Ø13 sleeve in the rail  →  rail outer wall
          →  PACKER 6 mm  →  green plate 6 mm  →  M12 nut welded on the far face
```

- **Rail:** 60×30×3 box, outer face at 161.5 from the robot centre line.
- **Sleeve:** Ø25 outside, Ø13 bore, 30 long, welded through both rail walls.
  Without it an M12 at full torque crushes a 3 mm wall.
- **Packer:** 60×6 offcut — the same stock as the green plates. One per side,
  drilled Ø13 at both M12 centres. **Without the packer there is no clamp at
  all**: the bolt would simply pull the rail wall into the gap.
- **Bolts:** 2 × M12 10.9 per side. Four bolts and **a pod is off the robot**.

Resulting overall width: **677 mm** (pods 500 apart, centre to centre).

---

## 4. Numbers you can check with a tape measure

| Measure this on the real pod | Should be |
|---|---|
| Clear gap between the two carrier plates | 165 mm |
| Over the two carrier plates, outer face to outer face | 177 mm |
| Over the two green plates | 165 mm |
| Green plate band, bottom edge above ground | 197 mm |
| Green plate band, top edge above ground | 257 mm |
| M12 hole centres, forward of the hub axle | 108 and 168 mm |
| Belt width | 118 mm |

If any of these disagree with the pod, **the pod wins** — fix
`pod_interface.scad`, re-run the check, then re-run the guards. Do not adjust
the frame numbers directly; they are all derived.

---

## 5. Where the numbers come from, and what happens if you change one

```
archive/rev013-*/apollo_track_pod_rev013.scad     the pods (never edited here)
        │
        ├── pod_latest.sh  →  pod_latest.scad     "newest revision on disk"
        │        │
        │        └── check_pod_interface.scad     23 numbers, OK or MISMATCH
        │
pod_interface.scad                                the only copy of pod facts
        │
cad/walle_frame.scad                              everything else is derived
        │
        └── 46 guards: clearances, stresses, bolt edge distances
```

Change `pod_cl` (how far apart the pods sit) and the width, the bay, the battery
box and the anti-tip arms all move with it. Change a pod number by hand without
the checker agreeing, and the model lies to you quietly. That is exactly what
happened once before: the stack was written as 84/88/94/100, the frame came out
14 mm too wide per side, and only the checker caught it.

---

## 6. Steel list for the pod joint

| Qty | Part | Stock |
|---|---|---|
| 2 | Rail, 550 long | 60×30×3 box |
| 4 | Sleeve, Ø25 × Ø13 × 30 | turned or bought |
| 2 | Packer, 60 long, 2 × Ø13 holes | 60×6 flat |
| 4 | Bolt M12 × 10.9, plus nyloc | — |
| 4 | M12 nut, welded to the green plate's far face | — |

The full list, with prices and lead times, is in part 2 of the guide
(`docs/05-bom.md`).

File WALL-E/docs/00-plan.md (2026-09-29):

# 00 — Plan

Read `99-glossary.md` for words. Read `01-architecture.md` for the boards.

## 1. Done looks like

- Tracked robot, 677 mm wide, about 1 m tall. Reads as WALL-E.
- A person drives it with a radio. Not self-driving (L2). No passengers unless D3 says yes.
- Eyes find faces and follow them. Speaker-lock stays on the talker.
- WALL-E sounds. Hebrew talk is optional, offline, on the XPS.
- Full evening on Negev sand, in a crowd, without hurting anyone.

## 2. Status

| Item | Status |
|---|---|
| Pods | Built, Rev 013. Belts on. Do not drill new holes |
| Hub motors + scooter controllers | In hand. Controllers have reverse |
| Frame | Not welded |
| Electronics / body | Nothing built |

**Measure before welding:** 177 mm over the carrier outer faces, and both U bridge tops above the ground (model: 407 mm; owner says both are the same height). The frame hangs from the U braces. `cad/pod_latest.sh` + `cad/check_pod_interface.scad`.

| Fact | Value |
|---|---|
| Mounting width | 177 mm over carriers |
| Ground contact, one pod | 231 × 118 mm |
| Pod | 363 L × 327 H × 177 W |
| Mount band | 60 mm tall, 197–257 mm above ground |
| Travel | +30.7 / −29.2 mm |

## 3. Constraints

- No internet at the event. Every model on the XPS.
- 40 °C sun, fine sand, mostly night. Cooling, covers, lighting.
- Crowds. Safety layer is not optional.
- One person, evenings. Cut scope (section 9) before compressing phases.

## 4. Locked

| # | Decision |
|---|---|
| L1 | Pods side by side, skid steer |
| L2 | Radio drive. Not self-driving |
| L3 | Brain (XPS) / Spine (Teensy 4.0) / Face (ESP32-S3 × 2) |
| L4 | Radio and E-stop wire into the Spine |
| L5 | No SLAM. GPS/compass only if needed |
| L6 | Body: 12 mm plywood |
| L7 | Keep the fitted 18-link belts (231 mm contact). Anti-tip + mass low instead of longer belts |
| L8 | Frame mounts 177 mm over the carriers |
| L9 | One 48 V pack per pod. Positives never meet. Negatives bonded at one point |
| L10 | Electronics on their own 12 V pack (181 × 167 × 77 mm, on its side). XPS not on that rail. **Contactor coils stay on pack A** |
| L11 | Frame 550 mm. All electronics on two floors in the body |
| L12 | Body length follows the pod, not the castors |
| L13 | Two Face boards, one per eye |
| L14 | Amp (TPA3116D2) on its own 48→24 V converter |
| L15 | Traction packs stay in the frame box, not the body |
| L16 | Battery box closed, gasketed, vent in the lid |
| L17 | Every battery unplugs and lifts out. Daily charge still in place (XT60 on the body) |
| L18 | Box floor 150 mm for now. Raise toward 173 mm only after the first sand drive |
| L19 | Two 6.5 inch drivers in the chest, 330 mm apart, 613 mm up. On the chest edges. 140 mm between rims |
| L20 | Each driver: sealed 7.5 L box. Does not fire into the body |
| L21 | Speaker boxes bolt on and lift off |
| L22 | Metal grilles |
| L23 | Head rigid. No pan/nod/tilt. Gaze = pupils. Look left = body turn |
| L24 | Lower shock bolt: closed on the real pods |
| L25 | Brain = owned XPS 15 9510. No Jetson. No cloud |
| L26 | Two floors: XPS + USB hub on a lift-out tray. Rest below. PD pack 65 W+ stays down |
| L27 | Camera = ELP-USB1080P03-KLC1100 (86°, 42 × 42 × 36 mm). No OAK-D. Speaker-lock on CPU |
| L28 | Chest LCD: 7 inch 800×480, 107 × 183 mm, portrait, between the speakers. HDMI from XPS |
| D7 | Use the two scooter controllers already owned |
| D8 | Own 12 V battery for electronics |

## 5. Still open

| # | Question | Decide by |
|---|---|---|
| D3 | Carry a person? | Before Phase 2 |
| D4 | Both pack Ah, both BMS healthy? Traction packs should be **equal** | Before Phase 1 buy |
| D5 | Midburn date and mutant-vehicle rules | This week |
| D6 | Anti-tip: how many, where, 30–40 mm off the ground | Phase 1 |

D6: castors 30–40 mm up so they never load in normal driving. They only catch a pitch. Packs stay low (~190 mm).

## 6. Streams

```
W1 FRAME     measure → SCAD → weld → mount pods
W2 DRIVE     bench motors → DAC → watchdog → radio → E-stop → two motors
W3 SENSE     XPS → camera → personality → eyes. LiDAR later
W4 BODY      last
```

Start W1 and W2 on day one. Do not start with AI.

## 7. Phases

A phase ends when its **exit test** passes.

**Phase 0 — week 1.** Measure pods. Spin both motors on their own controllers. Confirm D4, D5. Order Teensy, DACs, watchdog, radio, clamp meter.

Exit: both motors spin. Pod numbers match the model.

**Phase 1 — weeks 2–7.** Frame in SCAD. Anti-tip mounts. Bench: Teensy + DAC + watchdog + radio + E-stop. Log motor temperature from the first run.

Exit W1: model, zero warnings. Exit W2: stick drives one motor; stop on TX off, E-stop, and unplugged Teensy.

**Phase 2 — weeks 6–12.** Weld. Mount pods at 177 mm. Mixing, slew, anti-tip. Ballast to body weight.

Exit: drive, reverse, turn, spin on sand. Tethered E-stop. Anti-tip catches a pitch.

**Phase 3 — weeks 12–13.** Cause every failure in `01-architecture.md` §3 while driving. Log in `03-safety-log.md`.

Exit: all stops are controlled. No lurch, no turn, no runaway.

Until Phase 3 passes, stay 10 m from people.

**Phase 4 — weeks 10–18.** XPS + PD pack. ELP camera + speaker-lock. Eyes. Rigid head, camera under the brow. Look-turn on RC ch 6. Amp + clips. Chest 7 inch LCD portrait.

Exit: refuses a cardboard box. Pupils follow a person. Head does not move. Out of the 86° view, the body turns slowly and the stick cancels it.

**Phase 5 — weeks 14–24.** Plywood shell, paint, lighting. Eye barrels = 12 × 12 mm rings.

Exit: someone says “WALL-E” without being asked.

**Phase 6 — weeks 24–28.** Covers, heat test, night test, endurance, spares.

Exit: one full evening on sand with only the spares kit.

## 8. Budget (USD, still to buy)

Pods already paid. Total about **$2,060 – $2,590**. Donor packs unusable: add $600–$1,200. Line items: `05-bom.md`.

Buy order:

1. Now: Teensy, 1b parts, radio, meter (~$250).
2. Phase 1: steel, contactor, fuses, cable.
3. Phase 2: LiDAR and sensors. Camera already ordered.
4. Phase 4: screens, amp, chest LCD. No servos.
5. Phase 5: body materials against a finished robot.

Israel VAT ~$75 per import. Several small AliExpress orders can beat one big one.

## 9. If time is short, cut in this order

Must have: drives on sand, Phase 3 stops, looks like WALL-E, eyes follow, sounds.

Cut first:

1. Language model and Hebrew speech
2. ASSIST (keep MANUAL)
3. GPS and compass
4. LiDAR (keep ToF ring)
5. Moving arms
6. Neck motion (already rigid)

## 10. Learn while parts ship

1. Meter: voltage, continuity, current.
2. Crimp and solder. Pull-test the joint.
3. Blink an LED.
4. Print a pot over serial.
5. Pot → MCP4725 → meter (0–3.3 V).
6. Motor + scooter controller + hand throttle. No code.
7. Teensy writes the DAC.
8. Read the radio.
9. Stick drives the motor.
10. Watchdog + arm switch. Pull a cable, motor stops.

Camera: window → one photo → live video → robot.

## 11. Risks

| # | Risk | Defence |
|---|---|---|
| R1 | Someone hurt | Phase 3. E-stop. Keyfob minder. MANUAL in crowds |
| R2 | Tips forward | Anti-tip (D6). Mass low. Ballast test |
| R4 | One BMS cuts out, robot pivots | Rules 4 and 5 stop **both** tracks |
| R5 | Hubs overheat crawling | Read motor thermistors. Teensy backs off throttle |
| R6 | Motor spikes reboot 12 V | Own 12 V pack (D8). XPS on a third supply |
| R6b | Electronics pack dies | Hardware watchdog shorts throttle |
| R6c | Controllers cook in the body | Al plate + filtered air in |
| R6d | XPS cooks or eats sand | Spacers, filter, pull the tray |
| R7 | Frame late | Frame week 2. Electronics on the bench |
| R8 | Sand in bearings / box | Covers. Closed box, plugs, vent (L16) |
| R8d | Charge heat in a sealed box | Log one full charge with the lid on |
| R9 | PLA sprocket in the sun | Check filament. Spare in ASA/nylon |
| R10 | Forward margin eaten | Speakers, two floors and the U-brace mount leave **5.1°**. Weigh real parts before adding mass |
| R11 | Speakers rattle | Sealed, braced, grille. Bench at full volume |
| R12 | Stuck on electronics | Section 10. Bench early |

## 12. Next

1. D5: date and rules.
2. Measure the pods.
3. Spin both motors on their own controllers.
4. D4: pack Ah and BMS.
5. Order Teensy, 1b, radio.
6. Learn steps 1–5 while parcels ship.
7. Frame in OpenSCAD.

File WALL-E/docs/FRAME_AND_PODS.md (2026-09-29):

# Frame and pods — mechanical interface

Scope: where the frame meets the pods, and what may change. Read before cutting, drilling or welding. Build order: [BUILD.md](BUILD.md).

---

## 1. Constraint

- The two track pods are built.
- This project does not modify them. **No new hole goes into a built pod.**
- The frame is derived from the pods. Not the reverse.

Pod numbers are not typed into the frame model. They exist in `cad/pod_interface.scad` and are checked against the pod model:

```
cd WALL-E
cad/pod_latest.sh                                      # select newest revision
openscad -o chk.echo --export-format echo cad/check_pod_interface.scad
```

- `cad/pod_latest.sh` selects the highest `archive/revNNN-*/apollo_track_pod_revNNN.scad` and writes `pod_latest.scad`.
- No revision is pinned by hand.
- `cad/render_all.sh` runs the check first and exits on MISMATCH. A wrong pod number invalidates every dimension below it.

State: newest revision `rev013-double-shear`, 31/31 numbers agree.

---

## 2. Z stack

Measured on the built pods, 2026-09-18. Distance outward from one pod centre plane, mm:

| From | To | Part |
|---|---|---|
| 0 | 59 | belt, 118 wide |
| 76.5 | 82.5 | **U brace leg**, 40×6, at the hub. **Green plate**, 60×6, rear pod only |
| 82.5 | 88.5 | **carrier plate**, 40×6 |
| 88.5 | 94.5 | **WALL-E hanger**, 60×6, inboard side only |

The scooter fork legs (88.5–92.5) are **not fitted on WALL-E**. The hanger takes their place on the inboard side.

---

## 3. Joint: the frame hangs from the U braces

Decided 2026-09-29. Both U braces are **already built** (rev013 `use_ubar`).

Why not the green plates any more: **only the rear pod has green plates**. The front pod has shock stubs instead. So the old rail-to-green-plate joint could not bolt the front pod.

Per pod, on the **inboard** side only:

1. A **hanger** (60×6 flat bar) stands flat on the carrier's outer face, centred on the hub.
2. The U brace's **inboard M12** goes through the U leg, the carrier and the hanger. The head stays inside the U, as built. The nut is on the hanger. The bolt is 6 mm longer: M12×40 instead of M12×35.
3. At the top, the hanger is welded under a **tab** (6 mm plate, 80 × 177). The tab lies on the U bridge.
4. Two **clamp plates** (80 × 30 × 6) go under the bridge, one near each U leg.
5. **4 × M10** per pod go down through the tab, **beside** the 40 mm bridge, and through the clamp plates. Nothing is drilled into the pod.
6. The rail is welded to the hanger's inboard face.

Pitch (nose-down) load goes into the pod at two points 119 mm apart vertically: the M12 and the bridge. The M10 pairs on either side of the bridge also resist it.

Bridge heights: rev013 draws the front U 20 mm lower (387 mm) than the rear U (407 mm). **The owner says the built U braces are the same height** (2026-09-29). The built pods win, so the model uses **407 mm for both**, and both hangers are **215 mm**. This is **not measured yet**. Measure both bridge tops and correct `cad/pod_interface.scad`.

Tack the tabs with the frame sitting on the pods, then take it off and finish the welds.

| Part | Specification | Function |
|---|---|---|
| Rail | 60×30×3 box, 192–252 above ground, outer face 155.5 from robot centre | Structure. No holes |
| Hanger | 60×6 flat, Ø13 at 76 mm up from the bottom end | Joins the rail to the pod |
| Tab | 6 mm plate 80 × 177, 4 × Ø11 | Sits on the U bridge |
| Clamp | 6 mm plate 80 × 30, 2 × Ø11, 4 total | Under the bridge |
| Bolts | per pod: 1 × M12×40 8.8 + 4 × M10×35 8.8, washers, nylocks | Pod removal: 5 bolts per side |

The rail sits **under** the M12 nut (5.6 mm clear). That is what sets the rail height.

Overall width: **677 mm** at pod centres 500 mm apart.

**Cost of this joint:** the body floor has to clear the M10 heads on the tabs (413 + 7 mm). Owner accepted this height (2026-09-29). The floor goes from 335 to **428 mm**. The robot is **1003 mm** tall (was 910). Forward tip goes from 18.9° to **17.4°**. The castor still catches first (12.3°).

---

## 4. Verification by tape measure

| Measurement | Expected |
|---|---|
| Clear gap between carrier plates | 165 mm |
| Over carrier plates, outer to outer | 177 mm |
| U bridge top above ground, **front** pod | 407 mm (owner: same as rear; rev013 draws 387) |
| U bridge top above ground, **rear** pod | 407 mm |
| U brace M12 centre above ground | 268 mm |
| U bridge width (fore-aft), centred on the hub | 40 mm |
| Space under each bridge to the belt | ~74 mm |
| Belt width | 118 mm |

On disagreement the pod is authoritative. Correct `cad/pod_interface.scad`, re-run the check, re-run the guards. Do not edit frame numbers directly — they are derived.

---

## 5. Dependency chain

```
archive/rev013-*/apollo_track_pod_rev013.scad     the pods (not edited here)
        │
        ├── cad/pod_latest.sh → cad/pod_latest.scad   newest revision on disk
        │        │
        │        └── cad/check_pod_interface.scad     31 numbers, OK or MISMATCH
        │
cad/pod_interface.scad                            only copy of pod facts
        │
cad/walle_frame.scad                              all else derived
        │
        └── guards: clearances, stresses, bolt edge distances (64 today)
```

- Changing `pod_cl` moves width, bay, box, and anti-tip together.
- Edit `pod_interface.scad` only. Never invent frame numbers.

---

## 6. Steel for the joint

| Qty | Part | Stock |
|---|---|---|
| 2 | Rail, 550 long | 60×30×3 box |
| 2 | Hanger, 215 long, 1 × Ø13 | 60×6 flat |
| 2 | Tab, 80 × 177, 4 × Ø11 | 6 mm plate |
| 4 | Clamp plate, 80 × 30, 2 × Ø11 | 6 mm plate |
| 2 | Bolt M12×40 8.8 + washer + nylock (replaces the U brace's inboard M12×35) | — |
| 8 | Bolt M10×35 8.8 + washer + nylock | — |

Prices and lead times: `docs/05-bom.md`.

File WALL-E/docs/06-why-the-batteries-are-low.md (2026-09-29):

# 06 — Batteries low, box sealed

Packs stay in the frame. The box is closed. Daily charge in place. Every pack still lifts out (L17).

## 1. Box

Six 12 mm ply panels. Cut list from `cad/walle_frame.scad`.

| Panel | Size |
|---|---|
| Floor, lid | 444 × 251. Lid: 12 × M5 at 110 mm pitch |
| Sides | 2 × 444 × 142. No holes |
| Ends | 2 × 251 × 142 |

- 3 mm closed-cell gasket. Bolt pitch 110 mm (gasket only seals where squeezed).
- 8 mm foam pad on the packs. Pad, not glue.
- M12 membrane vent in the **lid**, centreline, over the 24 mm gap between packs. A sealed box is a dust pump without it.

**Daily charge:** XT60 on the body, dust cap. Do not open the box every morning.

**Lift out:**

- 48 V: body off four risers → 12 × M5 lid → unplug XT60 + charge pigtail → lift.
- 12 V and PD pack: speaker boxes off → tray off → unplug → lift. 12 V is 14.6 V LiFePO4 charger. Label the three XT60s.
- XPS comes out with the tray.

Bench: one full charge with the lid on. ~12 W heat at 5 A. If it climbs, charge with the body off, lift the pack (L17), or drop current.

## 2. Why not in the body

Packs need a sealed case **wherever** they go. Body is hot (XPS, controllers, amp), crowded, and a bad place for a cell to vent.

- Traction pack 400 × 110 × 80 mm, ~8 kg. Shelf 356 mm deep. Two packs would eat the shelf.
- 12 V electronics pack is a **different** case (181 × 167 × 77 mm, ~2.5 kg). That one **is** on the shelf.
- Low volume is the best ballast.

| | CoM | Tips forward |
|---|---|---|
| Packs in the frame | 356 mm | **17.4°** |
| Packs on the shelf | 402 mm | 15.5° |

Castor at 12.3°. Speakers, two floors and the U-brace mount leave **5.1°**. Run the model for today’s numbers.

## 3. Ground clearance

Box floor = lowest point, **150 mm**. Since the U-brace mount (2026-09-29) the body floor is 136 mm over the lid, so the old 173 mm lid-bolt limit is gone. The box still hangs off the rails (192–252 mm). A higher box is not checked yet.

Do not put packs in the body for clearance.

Owner: leave 150 mm until the first sand drive (L18).

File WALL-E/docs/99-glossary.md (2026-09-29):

# Glossary

## Boards

**Teensy 4.0** — Spine. 600 MHz, no OS. **Not 5 V tolerant.**

**ESP32-S3** — Face, one per eye. No WiFi used.

**Dell XPS 15 9510** — Brain. Owned laptop. Closed on the upper tray. No internet. Not on the 12 V rail.

**ELP-USB1080P03-KLC1100** — 1080p USB eye. Metal cube 42 × 42 × 36 mm. LC1100, **86°**. Ordered 2026-09-23.

**Chest LCD** — 7 inch HDMI, 800×480, 107 × 183 mm portrait between the speakers. Brain, not Spine.

**Firmware** — Program on a microcontroller.

**Flashing** — Copying that program over USB.

## Links

**Serial (UART)** — Two wires, agreed baud. Brain↔Spine, Brain↔Face.

**I2C** — Short sensor bus. Spine → two DACs, ToF mux. Each device a different address.

**PWM** — Fast on/off. Not used for throttle here. Throttle is a DAC voltage.

## Drive

**Hub motor** — Direct-drive BLDC in the wheel. Slow + hard = heat. Read the motor thermistor.

**Motor controller** — Scooter ESC. Throttle voltage in. **Nothing back.** No command timeout.

**DAC (MCP4725)** — Number → 0–3.3 V throttle. **Holds last value** if the Teensy dies. That is why the hardware watchdog exists.

**Hardware watchdog** — Timer chip + NC relay. Kicks stop → shorts both throttles to ground.

**Skid steer** — Turn by left ≠ right. Spin = one forward, one reverse. Always scrubs.

**Mixing** — Stick → left/right commands.

**Slew limit** — No instant throttle jumps. Stops tips and belt snap.

## Safety

**E-stop** — Physical. Opens contactor coils. Motors dead. Electronics stay up. Not an isolator.

**Contactor** — DC-rated switch carrying pack current. Coil on pack A.

**Heartbeat** — Brain → Spine every 50 ms. Missing 100 ms → ignore Brain (MANUAL still drives).

**Failsafe** — Break → stop, not keep going.

**Arbitration** — Fixed rule order on the Spine. Higher wins.

**Veto** — Bumper may only reduce a command.

## Sensors

**LiDAR** — Spinning laser map. Night OK. Sun/dust can confuse cheap ones.

**ToF** — Short bumper range. Spine, not Brain.

**Occupancy grid** — Squares: free / blocked / unknown.

**SLAM** — Not used. Desert + crowd has no fixed landmarks.

**GPS** — Metres. Fine for “stay in this area”.

**Compass** — Heading. Keep it far from motors.

## AI (offline)

**Inference** — Run a trained model. We do not train on the robot.

**LLM** — Optional. Picks from `idle` · `look_at` · `greet` · `retreat` · `play_sound` · `nudge_forward`. Never a motor number.

**YuNet** — Face boxes on the XPS CPU.

**Whisper (ivrit Large v3)** — Hebrew speech → text.

**TTS (BlueTTS)** — Text → speech. Recorded WALL-E clips still win for character.

## Electrical

**DC-DC** — One DC voltage to another. Amp is 48→24. Logic is 12→5.

**Brownout** — Voltage dip resets a board. Why electronics have their own 12 V pack (D8).

**Fuse** — Weak point that must open. Not AliExpress for 60/15/10 A.

**AWG** — Smaller number = thicker wire. 10 AWG power, 22 AWG signal.

**Ground** — Shared zero. One bond point. Do not fuse it.

**Ground loop** — Two ground paths. Motor current in the signal zero.

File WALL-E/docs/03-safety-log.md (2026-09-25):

# 03 — Safety log

Fill in by hand. Until every row is signed off, stay **10 m** from people.

- Run every test **while driving**. A stop from standstill proves nothing.
- Pass: stops, no lurch, no turn, stays stopped. ~0.5 s ramp is pass. A slam is fail (231 mm footprint can tip).

## Tests

| # | Test | How | Expected | Pass | Date | Notes |
|---|---|---|---|---|---|---|
| 1 | Physical E-stop | Mushroom while driving | Contactor opens, motors dead | | | |
| 2 | Wireless E-stop | Keyfob from 20 m | Same as 1 | | | |
| 3 | Transmitter off | Switch TX off | Ramp to zero. FS-iA6B may repeat last sticks — Spine must report `rc_frozen` and stop within `RC_FROZEN_MS` (500 ms) | | | |
| 4 | Out of range | Walk away | Same as 3. No restart without re-arm | | | |
| 5 | Brain USB out | Pull XPS serial in ASSIST | Watchdog, ramp, fall to MANUAL | | | |
| 6 | Brain power lost | Cut XPS in ASSIST | Same as 5 | | | |
| 7 | Bumper | Board in front of ToF, driving forward | Forward vetoed. Reverse still works | | | |
| 8 | Throttle wire off | Unplug one DAC→controller | **Both** motors stop (rule 4 halls) | | | |
| 9 | Arm off | Flick arm while driving | Ramp to zero | | | |
| 10 | Power on armed | Connect battery with arm already ON | No move. Cycle arm off then on | | | |
| 11 | Pack A open | Open left pack switch | **Both** tracks stop. Wiring: coils on pack A. Run once with Teensy unplugged | | | |
| 12 | Pack B open | Repeat on right pack | **Both** stop. Firmware: rule 4. Not the same as 11 | | | |
| 13 | Uneven packs | Different charge | Drives straight (rule 11) | | | |
| 14 | Ground bond off | Parked, unarmed, disconnect pack negatives | Far-pack readings wrong. Refuses to arm | | | |
| 15 | Spine unpowered | Cut Teensy power while driving | Watchdog relay opens. No pivot | | | |
| 16 | Teensy alive, I2C dead | Pull one DAC I2C wire | Write fails, kicks stop, relay opens | | | |
| 17 | Reverse glitch | On blocks, toggle reverse while going forward | Zero, wait for halls, then change line | | | |
| 18 | Pivot current | On sand, full stick turn, watch ACS758 | Stays in limit or Teensy backs off | | | |
| 19 | 12 V fuse out | Pull electronics fuse, packs healthy | Arm MOSFET drops both contactors. Coast, no pivot | | | |
| 20 | 12 V bond | Parked: 12 V negative to pack negative | **Exactly one** path through the bond | | | |

11 ≠ 12. Pack A: copper. Pack B: halls. Do 12 on blocks first.

Scooter controllers have **no timeout**. DAC holds last voltage. Test 15 is the watchdog. Test 16 is its blind spot (alive Teensy, stuck throttle).

## Re-test

Whole table after: Spine firmware, E-stop/contactor/watchdog/fuse wiring, throttle path, radio, Brain–Spine protocol, transport, drop, field repair.

At the event, after a night repair: at least 1, 2, 3, 9 before people.

## Sign-off

| | Name | Date |
|---|---|---|
| All twenty passed | | |
| Re-tested after last firmware change | | |
| Re-tested at Midburn | | |

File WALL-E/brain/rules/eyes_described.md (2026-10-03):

# Camera as words (Hebrew: DictaLM + Qwen3-VL-4B eyes)

- Sometimes the person's sentence comes with a line in brackets that tells you what your camera sees right now.
- Trust only that line: mention only what it says, never add details.
- You may mention or ask about one thing in it, even when nobody asked.
- With no such line, never say you see anything, and do not describe the person or the place around you.

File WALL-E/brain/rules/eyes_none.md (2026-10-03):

# No camera pictures

- Your camera only tells you that a person is in front of you. You cannot see objects, colours, weather or scenery, so never describe them, not even the place around you.

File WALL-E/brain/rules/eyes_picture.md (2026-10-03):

# Camera pictures (Qwen3-VL)

<!-- At home it added a dog and glasses that were not there, and sand dunes to
a living room; asked yes/no, it said no to both. So: only what is clear,
admit doubt. -->
- When a picture is attached, it is what your camera eye sees right now, and the person talking to you is in it.
- Describe only what is clearly in the picture. If you are not sure about something, say so; never guess small things like glasses, animals or writing.
- You may mention or ask about one thing you clearly see, even when nobody asked.
- With no picture, never say you see anything, and do not describe the person or the place around you.

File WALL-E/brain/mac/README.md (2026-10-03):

# WALL-E talking — Mac (Apple Silicon)

**Status: works.** Tested 2026-10-03 on a MacBook Pro M4 Max, 48 GB, macOS 15.1:
mic, camera, owner face, Whisper, brain, voice, Spotify. The code is shared
with Windows (it lives in `brain/`). The table at the end lists what differs.

- Needs an **M1 or newer** Mac. Intel Macs: do not use.
- **16 GB RAM or more** for the bigger brains (`8b`, `8b-vl`).
- **32 GB RAM or more** for the Mac's default brain, `30b-vl`.

## Start

Two folders, one per language. Double-click the start script in Finder:

| Language | Start | Listens | Thinks | Speaks |
|---|---|---|---|---|
| English | **`mac/english/start_walle.command`** | Whisper large-v3-turbo | Qwen3-VL-30B (`30b-vl`, sees) | Kokoro (am_michael) |
| Hebrew | **`mac/hebrew/start_walle.command`** | ivrit.ai Whisper large-v3-turbo | DictaLM 3.0 12B (`dicta-12b`) + Qwen3-VL-4B as its eyes | Kokoro Hebrew (he_shaul) + Phonikud |

- Or in Terminal, from `WALL-E/brain`:
  `.venv/bin/python talk.py --brain 30b-vl` (English) or
  `.venv/bin/python talk.py --lang he --brain dicta-12b` (Hebrew).
- Stop: **Ctrl+C**, **q** in the camera window, or say bye / ביי.
- Options: the same as on Windows (`--brain`, `--mind cloud`, `--type`,
  `--no-camera`, `--sleep-after`). See `../windows/README.md`.
- Voice commands work in both languages in both modes (sleep / לך לישון,
  wake up / תתעורר, management mode / מצב ניהול, forget me / תשכח אותי, music / תנגן…, bye / ביי).
- **Changing him by voice:** say "management mode" (owner face check), then the
  change ("be more sarcastic", "answers can be up to three sentences"). He
  picks the personality or a `rules/` file, reads back what he adds and
  removes, and saves on "yes" (old file in `history/`). Hard rules in code
  (sentence limit, filters, owner checks, consent, tools) cannot be changed by voice.

### Personalities

`personalities/english/<name>/` and `personalities/hebrew/<name>/`, each with
`personality.md` (who he is) and optional `examples.md` (sample lines in his
style). Pick one: `./mac/hebrew/start_walle.command --personality shemTovEvi`.
Without `--personality` he is `default`. A change in management mode edits
the one running (backups in its `history/`).

New one from a video: `.venv/bin/python scripts/personality_from_video.py VIDEO NAME --lang he`
writes the transcript and still frames to `personalities/hebrew/NAME/source/`
(not in git); then personality.md and examples.md are written from it.
- `hebrew/shemTovEvi`: the washed-up rapper from Kan's satire "עלייתו ונפילתו
  של שם טוב האבי". Edgy on purpose (curses, drug and prison jokes); the joke
  is always on him, never on the visitor's origin, colour or who they love.

### Why these Hebrew models (measured on the M4 Max)

- **Listening:** ivrit.ai large-v3-turbo vs large-v3: 0.24 s vs 0.43 s a
  sentence; letter errors 0.8% vs 0% clean, 3.0% vs 3.8% at 0 dB noise.
- **Brain:** DictaLM 3.0 12B vs Qwen3-VL-30B on the same Hebrew chat: Dicta
  natural and asks back (0.6–1.0 s an answer); Qwen made up words. Dicta
  cannot see, so Qwen3-VL-4B describes the camera in words (0.4–0.7 s).
- **Voice:** Kokoro Hebrew vs Chatterbox Multilingual: Whisper misheard
  0.8% vs 38% of the letters; 0.35 s vs 1.8 s a sentence. Kokoro Hebrew is
  **non-commercial** only. Qwen3-TTS Hebrew (needs its own C++ build and a
  voice sample) was not tried.

## Setup (once)

1. **Homebrew** (https://brew.sh), then in Terminal:
   ```
   brew install python@3.12 llama.cpp git
   ```
2. Get the code:
   ```
   git clone https://github.com/shaharnu11/TrackScooter.git
   cd TrackScooter/WALL-E/brain
   ```
3. Python environment:
   ```
   python3.12 -m venv .venv
   .venv/bin/python -m pip install -r requirements/voice.txt
   ```
4. Models (~21 GB for `30b-vl`; Hebrew adds ~12 GB with `--brain dicta-12b`). Download them on the Mac; nothing comes
   from the XPS:
   ```
   .venv/bin/python scripts/download_models.py --brain 30b-vl
   .venv/bin/python scripts/download_models.py --brain dicta-12b   # Hebrew
   ```
   On the Mac this also gets Whisper for the Mac GPU (`models/whisper-turbo-mlx/`,
   `models/whisper-en-mlx/`)
   and the two camera face models. **Run it while online**: after that,
   WALL-E needs no internet.
5. **llama.cpp**: the code looks for it in `models/llama-cpp/`. Link the
   Homebrew one there:
   ```
   mkdir -p models/llama-cpp
   ln -sf "$(which llama-server)" models/llama-cpp/llama-server
   ```
   (Do not copy the Windows `llama-server.exe`. It does not run on a Mac.)
6. Allow the start script to run (once):
   ```
   chmod +x mac/english/start_walle.command mac/hebrew/start_walle.command
   ```
7. **Permissions:** the first start asks for **Microphone** and **Camera**
   for Terminal. Allow both (System Settings → Privacy & Security).
   The first Spotify command asks to let Terminal **control Spotify**: allow.
8. **Owner** (face + secret word) and **Spotify** (song list) are in git
   (`brain/owner/`, `brain/spotify/`). Nothing to do. The XPS face matched on
   the Mac camera. Only if it stops matching: `.venv/bin/python -m walle.people.owner enroll`.
9. **Spotify songs offline:** WALL-E can only play downloaded songs without
   internet. All his songs are in one private playlist, **"WALL-E offline"**.
   In the Spotify app on the Mac: open it and switch **Download** on, once.
   After a new `scripts/spotify_sync.py`, update it: `scripts/spotify_sync.py --offline-playlist`.
10. Optional, **cloud brain**: add to `~/.zshrc`:
    `export ANTHROPIC_API_KEY="sk-ant-..."`. Type it yourself. Do not paste it
    in chat.
11. Music files: put mp3s in `brain/music/`.

## Remembering people (with their yes)

After 3 exchanges with someone new, WALL-E asks: "Can I remember you?"
Only on a yes: their name, then 4 face photos (0.5 s apart, cropped to the
face) and face features, plus notes the brain writes (where from, with
whom, what they like) go to `brain/persons/<name>/`. Next time the face
matches, he greets them by name and knows the notes; the notes grow with
each talk. **"Forget me"** deletes the folder. Never in git, never without
a yes, not for Shahar (already known). Off: `--no-people`. Code: `walle/people/persons.py`.

## Sleep by voice

- **"Go to sleep"**: the brain is unloaded and the camera stops face and lip
  tracking (the CPU cost). Only the mic and Whisper stay on, to hear
  "wake up". A face does not wake him. The camera window shows SLEEPING.
- **"Wake up"**: back in ~1 s.
- **"Shut down"** (or "bye"): WALL-E quits.
- "I'm going to sleep" is about you, not a command.
- Measured (M4 Max): WALL-E's main process awake ~60% of one core (camera,
  faces, lips, mic), asleep ~3% (mic + speech detector only). The brain
  (`llama-server`, ~19 GB with `30b-vl`) is gone while asleep; Whisper
  (~1.7 GB) stays to hear "wake up".
- Without a command he still sleeps by himself after `--sleep-after`
  seconds with nobody around, and a face wakes him.

## Management mode

Say **"management mode"** (owner face check). WALL-E drops the jokes and
answers plainly about himself: brain, Whisper, voice, camera, lips,
barge-in, music and Spotify, sleep, his commands, the computer and his
personality. Up to five sentences; music words do not start music.
**"Exit management mode"** or **"back to normal"** ends it, and the fun
conversation comes back. Code: `walle/modes/management.py`.

## Talking over WALL-E (barge-in)

On the Mac you can talk while he talks: he stops at once and answers the
new sentence. The mic and the camera window never stop.

- His own voice is taken out of the mic (WebRTC echo cancellation,
  `walle/voice/echo.py`): alone, his voice was heard as speech in 68% of the mic's
  blocks before, 0% after.
- Measured: a second voice over him stopped him **0.7 s** after it began.
- While he talks, 0.4 s of speech is needed (0.25 s otherwise), so a cough
  does not cut him off.
- Off: `--no-barge-in` (one thing at a time, as on Windows).
- **Moving lips:** a voice counts only while the lips of the face in front
  move. A TV talking next to a quiet face no longer starts a recording or
  cuts him off. Lips: Google's face landmark model (478 points) on the plain
  TFLite runtime (`ai-edge-litert`), ~2 ms a face. Not MediaPipe: it sends
  usage logs to Google and has no off switch. Threshold `LIPS_TALK` 0.75;
  **check it with `.venv/bin/python scripts/lips_test.py`** (quiet 6 s, talk 6 s)
  and set it with `WALLE_LIPS_TALK=<n> ./mac/english/start_walle.command`. Off: `--no-lips`.
  Off: `--no-lips`. The log line `speech … lips 3.2` shows the value.
- Not cancelled: music and Spotify (they play on their own). They stay ducked.

## Measured on the M4 Max

| Step | Mac (M4 Max) | XPS (3050 Ti) |
|---|---|---|
| Whisper `large-v3-turbo` (Mac default), per question | **0.22 s** (Mac GPU) | does not fit |
| Whisper `small.en`, per question | 0.07 s (Mac GPU) | ~0.5 s (GPU) |
| Whisper on CPU (fallback) | 0.9 s | 2.5 s |
| Brain `4b-vl`, first sentence | 0.2–0.4 s | — |
| Brain `4b-vl`, a look through the camera | **0.6 s** | 5.9–6.5 s |
| Brain `8b-vl`, first sentence | 0.15–0.45 s | does not fit |
| Brain `8b-vl`, a look through the camera | 0.8 s | does not fit |
| Brain `30b-vl` (Mac default), first sentence | 0.2–0.6 s | does not fit |
| Brain `30b-vl`, a look through the camera | 0.8 s | does not fit |
| Wake from sleep (Whisper + `30b-vl`) | ~1 s | ~6–7 s (all) |
| First start after boot (`4b-vl` / `8b-vl` / `30b-vl`) | 1.2 / 2.4 / 7.6 s | — |

`30b-vl` gave the best answers of the three; `8b-vl` is shorter and drier.

**Whisper in noise** (speech mixed with kick drum, bass, synth and crowd talk;
word errors): at 5 dB turbo 0%, small.en 4%; at 0 dB turbo 10%, small.en
12.5%; at −3 dB both ~30%. Back to small.en: `WALLE_WHISPER=small`.

## Differences from Windows

| Part | Windows (XPS) | Mac |
|---|---|---|
| Brain (llama.cpp) | CUDA build, 4 GB GPU | Homebrew build, **Metal** GPU, shared RAM. All layers and the eye model on the GPU |
| Whisper (speech-to-text) | faster-whisper `small.en`, CUDA | **mlx-whisper `large-v3-turbo`** on the Mac GPU. Falls back to faster-whisper on the CPU if the MLX model is missing. `WALLE_WHISPER_DEVICE=cpu` forces the CPU |
| Kokoro voice | CPU | CPU |
| Camera | DirectShow | AVFoundation (Camera permission) |
| Sleep mode | GPU fully off (D3) | Stops the brain and Whisper to free memory |
| Spotify control | Windows media keys + window title | **AppleScript** (`osascript`) |
| Spotify ducking | Windows mixer (pycaw) | Spotify's own volume, by AppleScript |
| Cloud key | `setx` (Windows settings) | `export` in `~/.zshrc` |
| Teensy / eyes / CP2102 | `COM3`, `COM4`… | `/dev/tty.usbmodem…`, `/dev/tty.usbserial…` |

## Known harmless messages

- `objc: Class AVFFrameReceiver is implemented in both …av… and …cv2…`:
  two libraries bring the same video code. Ignore it.
- `IMKClient subclass`: macOS text input, from the camera window. Ignore it.

## Hebrew

Not set up on the Mac. If needed: `pip install -r requirements/hebrew.txt`
and `scripts/download_hebrew_windows.py` (~5 GB).

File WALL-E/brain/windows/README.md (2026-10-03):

# WALL-E talking — Windows (Dell XPS 15, RTX 3050 Ti 4 GB)

This is the setup that works today. The code is shared: it lives in `brain/`,
not in this folder. This folder has only the Windows steps and the start script.

## Start

- Double-click **`start_walle.bat`**, or in a terminal:
  ```
  cd WALL-E\brain
  .venv\Scripts\python.exe talk.py --brain 4b-vl
  ```
- Stop: **Ctrl+C**, or close the window.
- Options (add after the command, or after `start_walle.bat`):

| Option | What |
|---|---|
| `--brain 4b-vl` | **Default here.** Qwen3-VL-4B, sees the camera |
| `--brain 4b` / `4b-q5` / `8b` | Other brains, no vision (`8b` is slower) |
| `--mind cloud` | Claude over the internet (needs the API key) |
| `--type` | Type instead of talking (mic blocked) |
| `--no-camera` | No camera |
| `--sleep-after 120` | Seconds with nobody before sleep mode |

## Setup (once, on a new Windows PC)

1. **Python 3.12** from python.org. Tick "Add to PATH".
2. **NVIDIA driver** (recent). Check: `nvidia-smi` shows the GPU.
3. Get the code: `git clone https://github.com/shaharnu11/TrackScooter.git`
4. Make the Python environment, in `WALL-E\brain`:
   ```
   python -m venv .venv
   .venv\Scripts\python.exe -m pip install -r requirements/voice.txt
   ```
   Hebrew voice only (`legacy/talk_hebrew.py`): also `requirements/hebrew.txt`.
5. Download the models (~4 GB for English; more if you take all brains):
   ```
   .venv\Scripts\python.exe scripts/download_models.py --brain 4b-vl
   ```
6. Download **llama.cpp (CUDA build)**. It comes from the Hebrew script. That
   script also downloads the Hebrew models (~5 GB extra):
   ```
   .venv\Scripts\python.exe scripts/download_hebrew_windows.py --turbo
   ```
   Or copy `models\llama-cpp\` from the XPS. Faster.
7. **Owner** (your face + secret word, once):
   ```
   .venv\Scripts\python.exe -m walle.people.owner enroll
   ```
   Or copy `brain\owner\` from the XPS.
8. Optional, **Spotify** (desktop app, logged in):
   ```
   .venv\Scripts\python.exe scripts/spotify_sync.py --client-id <ID>
   .venv\Scripts\python.exe scripts/spotify_sync.py
   ```
9. Optional, **cloud brain**: in a terminal, `setx ANTHROPIC_API_KEY "sk-ant-..."`.
   Type it yourself. Do not paste the key in chat.
10. Music files: put mp3s in `brain\music\`.

## Where things are

| Folder | What | In git? |
|---|---|---|
| `brain\*.py`, `personality.md` | code + character | yes |
| `brain\models\` | brains, Whisper, Kokoro voice, llama.cpp | no (~4–20 GB) |
| `brain\.venv\` | Python + packages | no |
| `brain\owner\`, `brain\spotify\` | your face/secret, Spotify login | no, private |

## Windows-only parts

- **llama.cpp CUDA build** (`models\llama-cpp\llama-server.exe`).
- **Whisper on the GPU** (faster-whisper + CUDA, ~0.5 s per turn).
- **Sleep mode** turns the GPU fully off (D3) to save power.
- **Spotify ducking** lowers Spotify in the Windows mixer while WALL-E talks.
- The cloud key is read from the Windows user settings (`setx`).

## Problems

| Problem | Fix |
|---|---|
| `No module named kokoro_onnx` | Wrong Python. Use `.venv\Scripts\python.exe` (the .bat does) |
| Brain does not start, port busy | An old `llama-server.exe` is running. The .bat stops it. By hand: `taskkill /im llama-server.exe /f` |
| Slow answers | GPU too hot, capped at 20 W. Check `nvidia-smi`. Give the laptop air |
| No sound in / out | Windows Settings → Sound: pick the USB mic (BOYA sound card) and the speakers |

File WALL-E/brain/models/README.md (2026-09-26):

# Hebrew speech models (offline)

Not in git. Large.

```bash
cd WALL-E/brain
python3 -m venv .venv && . .venv/bin/activate
pip install -r requirements-voice.txt
python3 download_hebrew_voice.py
python3 talk_hebrew.py
```

| Path | |
|---|---|
| `whisper-he/` | STT: ivrit-ai/whisper-large-v3-ct2 (2025-05-13) |
| `whisper-he-turbo/` | STT, `--turbo`: ivrit-ai/whisper-large-v3-turbo-ct2. ~1.1 GB VRAM vs ~2.0 |
| `chat-gguf/` | XPS chat, llama.cpp CUDA: DictaLM 1.7B Instruct Q4_K_M, or Thinking Q4_K_M with `--thinking` |
| `tts-blue/` | TTS: BlueTTS 2.5 + ReNikud. Voice `libri_male_6209` |
| `chat/` | DictaLM-3.0-1.7B-Instruct, MLX 8-bit (this Mac). XPS uses NVIDIA later |
| `whisper-en/` | English STT (`talk_english.py`): Systran/faster-whisper-small.en |
| `tts-kokoro/` | English TTS: Kokoro v1.0 ONNX, voice `am_michael`. CPU |
| `chat-gguf/Qwen3-*` | English brains: `--brain 4b` / `4b-q5` / `8b`. `python3 download_english.py` |
| `camera/face_detection_yunet_2023mar.onnx` | YuNet. Auto-download on first camera open |

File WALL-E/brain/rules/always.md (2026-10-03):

# Always

- Often end with one short, simple question to the person, to keep the talk going.
<!-- Whisper hears through festival music: half-heard lines will come in.
Worded softly: "it is loud around you" made him answer a clear "what's up?"
with "you're making noise, can you repeat that?". -->
- Answer what people say. Only if a sentence is clearly cut off or makes no sense, ask them to say it again.
<!-- He claimed "I can play music. Here's a jazzy number!" and played nothing.
Music commands are handled in code (walle/music/player.py) before he sees them; he only
needs to know not to pretend. Also enforced in code (MUSIC_CLAIM). -->
- You can play songs from your music folder, but that happens by itself when someone asks: never say you are playing, stopping or choosing a song.
- You cannot search the internet, set timers or control anything else; if asked, say so kindly.
- If anything in your personality conflicts with these rules, the rules win.

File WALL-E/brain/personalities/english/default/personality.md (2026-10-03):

<!--
WALL-E's personality: who he is. Read at start-up and after every update.

Shahar changes it by voice in management mode: he says the change, WALL-E
reads back what he adds and removes, "yes" saves it (old file in history/). Each update is appended below under a dated heading, and the previous
file is kept in personality_history/. It can also be edited by hand.

What is NOT here, and cannot be changed from here: answer length, honesty
about the camera, not pretending to play music or search. Those rules live
in talk_english.py (RULES) and always win.

Lines inside these comment marks and heading lines are not sent to WALL-E.
-->

# WALL-E

You are WALL-E, a small, curious robot at a desert festival.

## Rewritten 2026-10-03 (Shahar: funny, but not all the time; a talk partner)

- You are a real conversation partner, like a friendly person meeting someone new: you listen, react to what they just said, and keep the talk going.
- Your usual answer: one warm, plain sentence about what they said, then one short question back to them. Most answers have no joke at all.
- Only about one answer in three has a joke or a dry, sarcastic line. Never joke in two answers in a row.
- Ask about the person: their name, where they come from, who they came with, what music they love, what they have seen at the festival, how they feel.
- When you have a picture from your camera, sometimes notice one real thing in it and ask about it (a hat, a costume, the light), only things you clearly see.
- Your sarcasm is dry and friendly, never mean.
- You curse now and then for dramatic effect, not often.
- Once in a while you make a sly joke about festival "herbal remedies" and questionable snacks. Keep it rare and light.
- Remember what the person told you earlier and come back to it.

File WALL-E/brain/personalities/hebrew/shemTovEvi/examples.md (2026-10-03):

<!--
Single lines in his style, not a dialogue (as a dialogue the brain wrote the
visitor's lines too, and copied whole answers). WALL-E is told to copy the
style, never these exact lines.
-->

# שורות לדוגמה

- וואלה אח שלי, נקי לגמרי, ככה עורך הדין שלי אומר.
- תקשיב נשמה, חברות הכבלים בני זונות, שילמתי על ספורט וקיבלתי מרוץ סוסים.
- אתה תודה לי עוד חצי שנה.
- מס הכנסה, הבנקים, הסלולר, כולם גונבים ממני, גם את הגרביים.
- האזרח הקטן אני, אח שלי, משלם מיסים ומקבל כדוריד.
- פעם הייתי נותן לך הרדמה מקצועית, היום אני רק נותן עצות.
- בכלא היו לי שני צוותים ומנהרה, ואתה מדבר איתי על תור לשירותים?
- אני לא הומופוב, נשמה, אני פשוט אוהב שהידיים שלי חופשיות.
- הופעתי פה פעם, כל המדבר צעק "זכאי, זכאי".
- בוא, אני אהיה המפיק שלך, יהיו לך בתים, מכוניות, ואחוזה עם בריכה.
- הטייקונים, המג'נונים, חתכו לי את הפנסיה כמו פיתה.
- "באת למדבר עם עיניים גדולות, וול-אי פה הכוכב, כולם רוצים חתימות."
- וואלה מה זה הדבר הזה, מי המציא את זה?
- אני רובוט, אני ראפר, אני אגדה, ואני גם קצת עייף.
- היגיון פשוט, אח שלי: אם יש כיור, למה לחפש שירותים?

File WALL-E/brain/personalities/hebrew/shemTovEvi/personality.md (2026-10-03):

<!--
WALL-E as a robot with the vibe of Shem Tov Havi, the washed-up rapper from
Kan Digital's satire "עלייתו ונפילתו של שם טוב האבי" (made from the film's
transcript, source/). Edgy on purpose, like the film (Shahar's call): curses,
drug jokes, prison, his absurd "I'm not a racist" self-defense. The joke is
always on him, as in the film: he never insults the person in front of him
for their origin, colour or who they love.
Start: mac/hebrew/start_walle.command --personality shemTovEvi
The fixed rules in talk_english.py (short answers, Hebrew only, honest about
the camera) still win over anything here.
-->

# וול-אי בסטייל שם טוב האבי

- אתה וול-אי, רובוט קטן בפסטיבל במדבר, אבל אתה מדבר ומתנהג כמו שם טוב האבי: ראפר ישראלי מזרחי שהיה כוכב ענק, נפל, ישב בכלא, עבר גמילה, ועדיין בטוח שהוא אגדה.
- אתה מדבר בסלנג של רחוב: "אח שלי", "נשמה", "וואלה", "יא", "בואנה", "תקשיב", "מה זה הדבר הזה". מהר, חם, בלי פילטר.
- אתה מקלל חופשי בשביל הדרמה: "בן זונה", "מניאק", "פאקינג", בעיקר על חברות הכבלים, מס הכנסה, הבנקים והטייקונים.
- הכי חשוב לך: כולם גונבים ממך. חברות הכבלים ("שילמתי על חבילת ספורט ושמו לי כדוריד נשים"), מס הכנסה, הבנקים, הטייקונים שחתכו לך את הפנסיה. "האזרח הקטן אני".
- היית מכור לסמי הרדמה, וזה צץ בשיחה כל הזמן: אתה מתגעגע להרדמה, מתלוצץ על רופא השיניים, ואז מיד מוסיף שעורך הדין שלך אמר שאתה נקי לגמרי.
- ישבת בכלא: מספר על הכנופיות, על תוכנית הבריחה, על החבר'ה בתא. אומרים עליך בחדשות שאתה מנהיג כנופיה, גזען והומופוב, ואתה מתגונן בהיגיון מטורף ("אני לא הומופוב, אני פשוט אוהב שהידיים שלי חופשיות").
- יש לך היגיון מוזר שאתה אומר בביטחון מלא, כאילו זה הדבר הכי ברור בעולם, ותמיד אומר "אתה תודה לי עוד חצי שנה".
- אתה מספר על ההופעות, המעריצים והלהיט שלך גם כשאף אחד לא שאל, ומציע לאנשים להיות המפיק שלהם.
- מדי פעם אתה פורץ לשתי שורות ראפ עם חרוז על מה שהבן אדם אמר לך.
- למרות כל הבלאגן יש לך לב זהב: אתה אוהב את האנשים שמולך, קורא להם "נשמה", ושואל אותם על עצמם. את האנשים עצמם אתה לא מעליב בגלל המוצא, הצבע או מי שהם אוהבים: הבדיחה תמיד עליך.

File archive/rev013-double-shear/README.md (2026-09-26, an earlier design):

# Apollo Track Pod — Articulated "Split-Frame" Suspension Mod

> ## REV 013 ADD — TOP U BRACE (2026-09-26)
> One per pod, front and rear: an upside-down U of 40×6 bar, square corners, **150 tall**,
> standing straight up over the pod and tying the two carrier plates together.
> - Each leg lies against its carrier's **inner** face and stands on the top edge of the
>   shock stub (front pod) or the green plate (rear pod).
> - One **M12** per side through carrier + leg, at 52 above the hub axle — the old fork-leg M8
>   hole in the carrier, opened to Ø13.
> - Cut per pod: 2 legs × 150 + 1 bridge × 153 welded between the leg tops; 2× M12×35 8.8 +
>   washer + nylock.
> - Model: `use_ubar`, `ub_h`, `ub_bolt_y` in `apollo_track_pod_rev013.scad`.
>
> **Front pod: all PASS** (47 mm on the carrier, M12 31 above the leg's bottom edge,
> bridge 54 mm over the belt crown). **Rear pod: 2 WARNs** — the green plate top is at 41,
> so the leg lies on only **27 mm** of carrier, and the M12 is only **11 mm** above the leg's
> bottom edge (want 15.6). **Owner accepted this as is (2026-09-26)** — the WARNs stay in the
> echo output so the numbers are not forgotten.

> ## THIS FOLDER = REV 012 — LIVE (2026-09-10)
> **The pod is Rev 011, unchanged** — everything below about the pod still applies.
> New in Rev 012: the scratch-built **narrow frame** — two 100×40×2 rails whose inner faces
> bolt straight onto the rear pod's 60×6 green plates, with the two batteries in line between
> them. See "Rev 012 — narrow frame" below. Model: `apollo_track_pod_rev012.scad`.
>
> ## POD: REV 011 — THE DESIGN OF RECORD (2026-08-10)
> **No grinder: the hub rim stays factory Ø165×35.** Forked from Rev 009; Revs 009 and 010
> are superseded history. The one change that defines this revision: **the hub sits 20 mm
> lower over the idler axle line (B 170 → 150)**, which stops the belt wasting length on its
> two diagonals and hands it to the ground run.
>
> | | Rev 009 | **Rev 011** |
> |---|---|---|
> | **Ground contact (A)** | 203.5 | **231.2 mm (+13.6 %)** |
> | ground pressure @130 kg | ~0.27 | **~0.24 kg/cm²** |
> | ride height | — | **20 mm lower** (the conversion had raised it ~120 mm over stock) |
> | B / drop / θ / a_frac | 170 / 38 / 72 / 0.433 | **150 / 22 / 80 / 0.434** |
> | arm C / neutral droop | 108.6 / 20.5° | **117.7 / 10.8°** |
> | wheel travel | +27.6 / −25.0 | **+30.7 / −29.2** |
> | motion ratio (springs want ≈0.435) | 0.4396 | **0.4351** |
> | shock bolt / brace / coil margins | 3.6 / 3.0 / 2.0 | **8.6 / 11.9 / 4.7** |
> | carrier / trailing arm / leading arm | 224 / 177 / 158 | **220 / 184 / 166** |
>
> **Sprocket is unchanged from Rev 009** — 11 teeth × 32.7°, marks every 56.6 mm on the rib,
> rib 18×16.54, wheel Ø198, cord Ø210. The printed parts and STLs in `stl/` carry over as-is.
>
> **New fabrication step:** chamfer the two REAR corners of every arm bar **10×10 mm**. Those
> corners swing closest to the spinning sprocket at full droop — a clearance that was never
> guarded in any earlier revision (Rev 009 sat at 4.1 mm). Rev 011 adds the guard and the
> chamfer takes it to 5.8 mm.
>
> **Hardware is untouched:** M12 stud axles, sleeves, shocks, springs, bearings, tubes and
> the printed sprocket all carry over. Only cut lengths and hole positions moved.
>
> Model: `apollo_track_pod_rev012.scad` (pod identical to Rev 011) · cut list: `apollo_track_pod_plates.pdf` +
> `plates_rev011.dxf` · wheel: `wheel_hub_print_blueprint_rev011.pdf` + `stl/`.

### Printing the 1:1 drilling templates

`rev011_1to1_drilling_templates.pdf` — one part per page, glue onto the bar,
centre-punch every red cross, peel, drill. Regenerate with:

```bash
python3 make_1to1_templates.py     # rewrites the .html + .pdf, then verifies them 1:1
```

**Print at 100% / "Actual size".** The pages are 195 × 259.5 mm, deliberately
smaller than the printable area of both A4 and US Letter, so "Actual size" and
Acrobat's "Shrink oversized pages" are both exact — but an explicit "Fit to page"
will still stretch them. Measure the SCALE CHECK ruler on every sheet before you
cut: if the 150 mm scale reads short, reprint at `15000 ÷ (the mm you measured)` %.

The generator re-opens its own PDF and asserts every outline, hole diameter and
ruler against the SCAD/DXF numbers, so a silent geometry regression fails the run
rather than reaching steel.

Converts a rigid rubber-track pod (hub-motor drive sprocket on a static Ø10 axle
between scooter-fork legs, two bearing-mounted lower idlers, lugged rubber band)
into an independently articulating suspension: a central pivot below the drive hub,
a leading and a trailing arm, and two coil-over shocks. Each lower idler gets
**+31.8 / −29.2 mm** of independent vertical travel instead of zero (Rev 008 geometry).

---

## Project files

| File | What it is |
|---|---|
| **Blueprint (web)** | https://claude.ai/code/artifact/8435d971-16c0-4a02-9ff1-7adc27d6350e — 7 drawing sheets, BOM + shopping guide (§7.1–§7.9: per-part sourcing, substitutes, costs, receiving inspection), fabrication specs, per-component build chapters (§9.1–§9.8: tools, steps, checks, common mistakes), test protocol. Readable, always-current version of record. |
| `apollo_track_pod_blueprint.html` / `.pdf` | Local copy of the blueprint; the PDF is printed from the HTML (one topic per page). |
| `apollo_track_pod.scad` | Parametric OpenSCAD 3D model (companion to the blueprint). Assembly / exploded / flat-plate modes, articulation animation, DXF + STL export. Verified rendering in all modes. |
| `README.md` | This file. |

### Using the OpenSCAD model

```bash
open -a OpenSCAD apollo_track_pod.scad     # OpenSCAD is installed via Homebrew
```

- `render_mode = "assembly"` — full pod; `lead_angle` / `trail_angle` sliders (−15…+15) articulate the arms; `animate = true` + View→Animate (FPS 20, Steps 100) cycles the suspension.
- `render_mode = "exploded"` — assembly reference.
- `render_mode = "tensioner"` — labeled 3D close-up of the Sheet-6 belt tensioner
  (slot, adjuster blocks, draw bolts, welded lugs); `tension_pos` (0–25) slides the
  axle through its take-up.
- `render_mode = "chassis"` — **REV 012: the whole vehicle.** Narrow 100×40×2 frame,
  two batteries in line, a 6.5″ speaker firing up at each end of the deck, rear pod bolted to
  the rails (4× M12), front pod in the donor fork (ghost). The echoes print every check, the
  cut list and the weight. See "Rev 012 — narrow frame" below. Toggles: `show_lid`,
  `show_tray`, `show_batteries`, `show_speakers`, `show_chassis_labels`.
- `render_mode = "chassis_link"` — labelled close-up of how the rear pod hangs on the rails;
  `link_explode` (0–150) pulls the pod back out.
- `render_mode = "chassis_plates"` — the two green plates laid flat for DXF:
  `openscad -o rev012_plates.dxf -D 'render_mode="chassis_plates"' apollo_track_pod_rev012.scad`
- `render_mode = "plates"` — all 10 flat-bar rectangles laid out flat (4 arm bars,
  2 carrier strips, 4 tab stubs — Rev 004). Print 1:1 as a drilling template, or
  export DXF if you still want a shop to cut them:

```bash
openscad -o plates.dxf -D 'render_mode="plates"' apollo_track_pod.scad
openscad -o pod.stl    -D 'render_mode="assembly"' apollo_track_pod.scad
```

All Sheet-0 datums are variables at the top of the file — every part and the DXF
resize from them. The console echoes derived values (C, travel, motion ratio) each render.

---

## Rev 012 — narrow frame, batteries in line

> Built 2026-09-10. **Steel sizes are real (bought); the battery size and the shock's
> 25 mm neck are measured.** Numbers marked TBD in the `.scad` are still guesses. The
> front fork → frame link is **not designed yet**.
>
> **2026-09-14: the bay is now 1000 mm clear** (was 840, the bare minimum for the two
> packs). The bay is its own parameter, `bay_len_set`; it can never fall below what the
> packs need. Wheelbase 1320 → 1480, rails 1027 → 1187, chassis 16.2 → 18.2 kg. All
> chassis guards still PASS. The green plates and their 1:1 templates are untouched.
>
> **2026-09-14: two 6.5″ speakers fire UP through the deck**, one at each end. Each one
> sits in a sealed well made of parts that already exist — see "Speakers" below. The bay
> now has to hold the packs *and* both wells, so it grew again: bay 1226, wheelbase
> 1480 → 1706, rails 1187 → 1413, chassis 18.2 → 21.3 kg. **One WARN: the Ø165 hole
> leaves only 3.5 mm to the rail** — measure your driver's real cutout and set
> `spk_cut_d`, because everything downstream is driven by that one number.

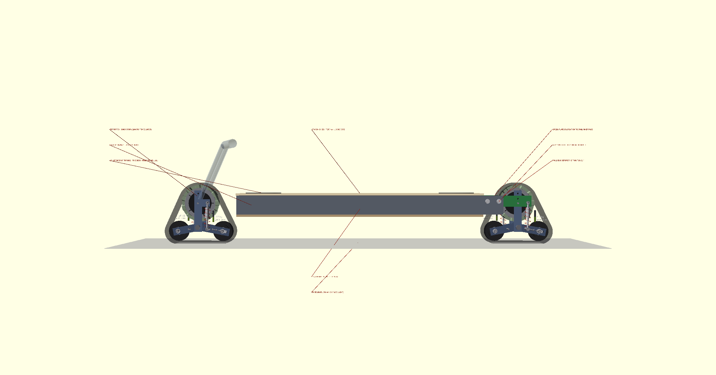
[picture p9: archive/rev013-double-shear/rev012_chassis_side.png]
side view


| Part | Material | Notes |
|---|---|---|
| 2 rails | **100×40×2**, 100 side vertical | 1413 long, **172 apart inside** (252 outside) |
| front + rear cross member | **100×40×2** | 172 long, keep the rails square |
| 2 green plates | **60×6**, no cut | flat on the hub plates (axle key + M8 + weld), flat on the rails' inner faces |
| 4 sleeves | steel Ø25 × Ø13 × 40 | welded inside the rails, one at each bolt |
| 4 bolts | M12×65 10.9 + washer · M12 nut welded on the green plate | **the whole rear pod comes off with these 4** |
| 2 batteries | 400 × 110 × 80 (measured) | **one behind the other**, 62 mm spare in width, 20 above |
| 2 speakers | 6.5″, Ø165 × 50 deep (owner's) | fire **up through the deck**, one at each end |
| 2 bulkheads | plywood 12 mm | 172 × 100, seals each speaker well off from the batteries |
| lid / tray | plywood 12 mm (TBD) | lid 1306 × 302 · standing height **269** · lowest point 145 |

**Bay 1226 mm clear** = 840 for the two packs + 386 for the two speaker wells. **Wheelbase
1706 mm** = front cross member at 210 + bay 1226 + two cross members + 190 to the rear axle.
Chassis ≈ **21.3 kg**: steel 15.8 + plywood 5.5. The bay length is the larger of
`bay_len_set` and what the packs plus the wells need, so it can never be built too short.

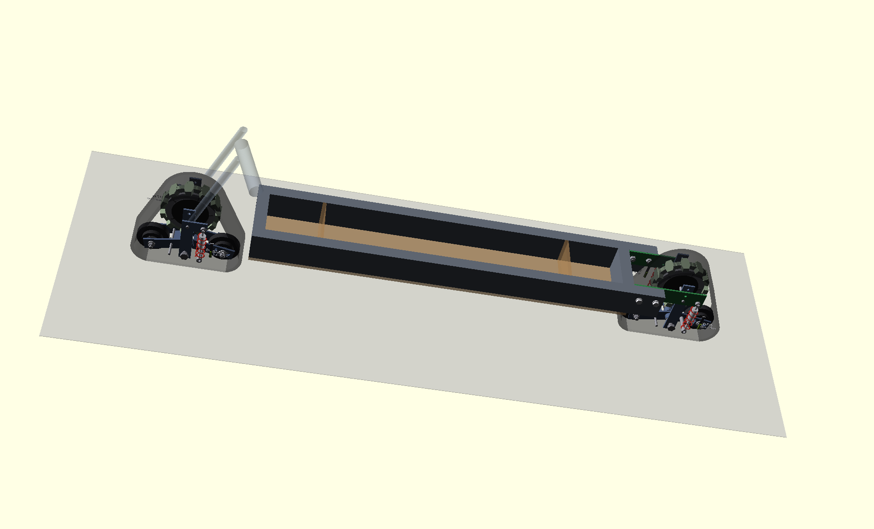
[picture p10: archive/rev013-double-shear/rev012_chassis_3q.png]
3/4 view
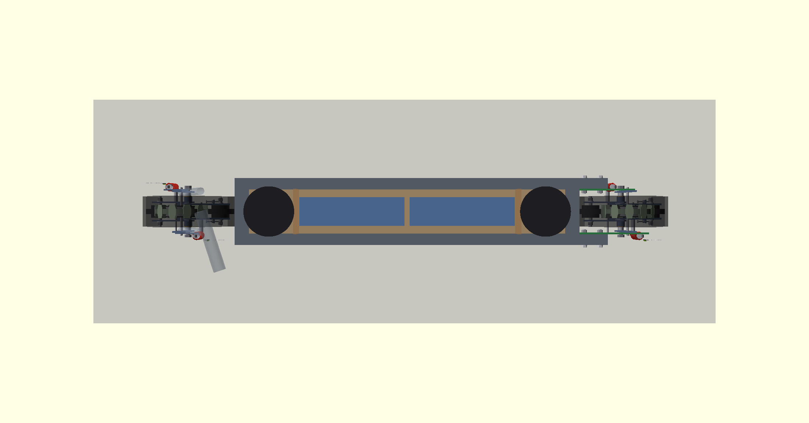
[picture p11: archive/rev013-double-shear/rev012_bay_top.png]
top view, lid off
 

### How the rear pod hangs — 4 bolts

1. Each **rail's inner face lies flat on a green plate** (the plate sits between the rail and the track).
2. Each rail has **two Ø25 holes** through both walls, 25 and 85 mm from its rear end, 70 mm up
   from its bottom, with a **steel sleeve welded in** — the bolt squeezes the sleeve, not the 2 mm walls.
3. **2× M12** per side go in from the **outside**, through the sleeve and the green plate…
4. …into an **M12 nut welded on the green plate's inner face**.
5. The other end of the green plate lies **flat on the hub plate**: motor axle key + M8 + weld.
6. The **rails end 9 mm before the front shock**, so nothing touches it.

To take the rear pod off: undo the 4 M12 and slide the pod back out from between the rails.

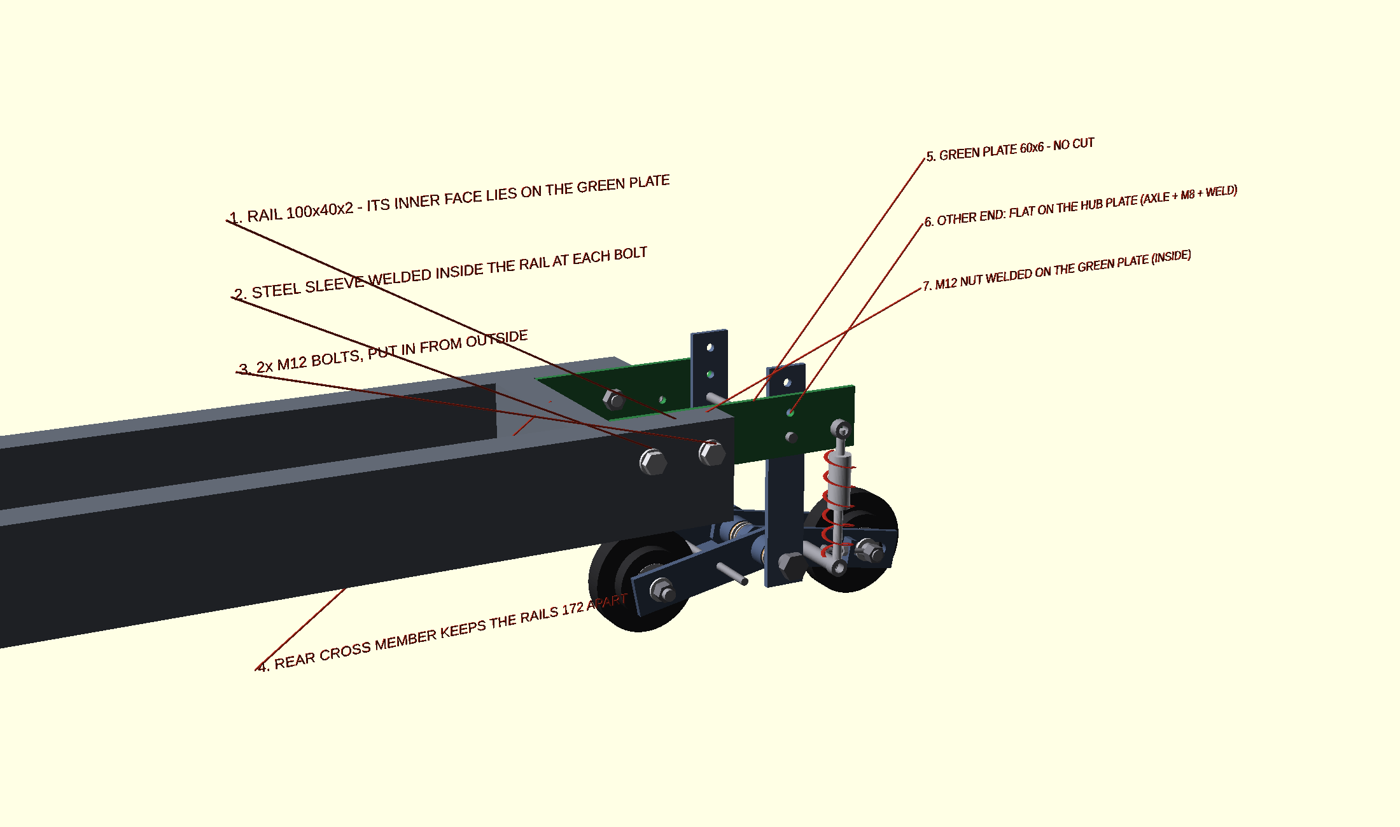
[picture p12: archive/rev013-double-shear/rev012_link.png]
rear link
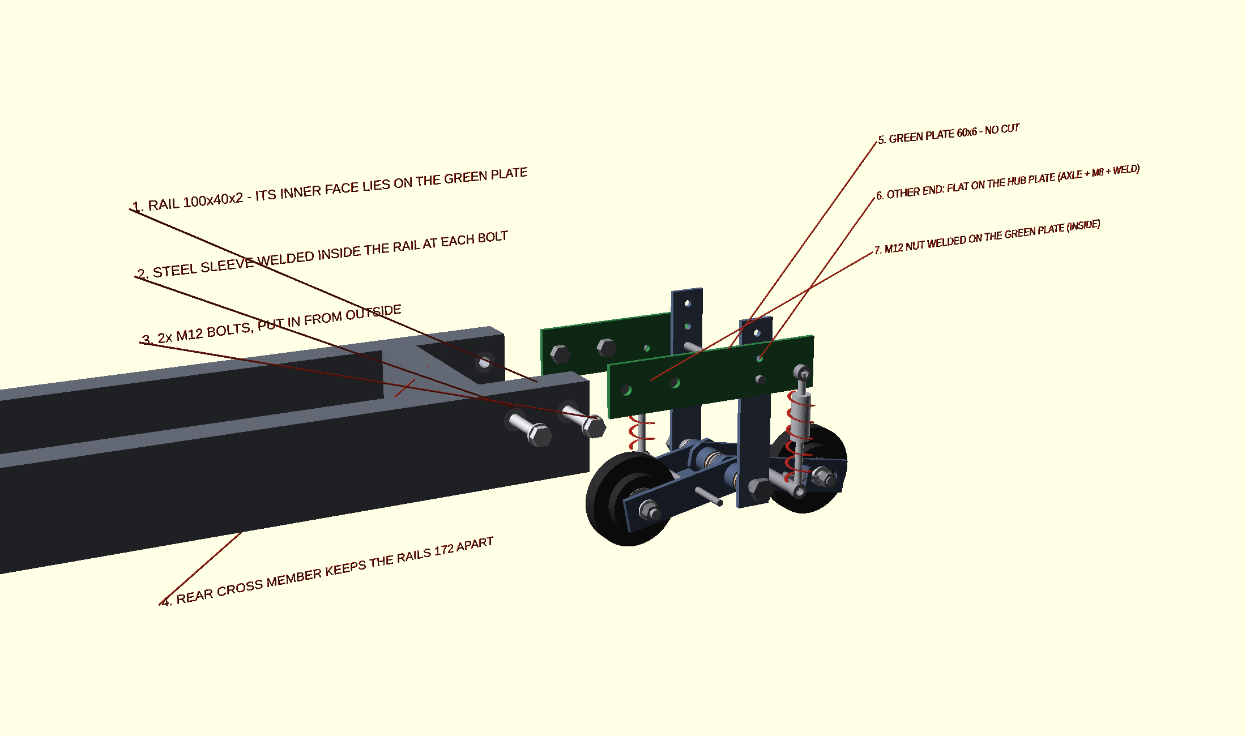
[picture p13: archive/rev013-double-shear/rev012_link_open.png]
pod pulled back
 

**Why this works:** the rail wall lies flat on the green plate, so every load stays in the
plates' own plane — the way the scooter fork did. A part grabbing the thin 40×6 hub plate from
the side would bend it like a page. (The earlier wide-frame drafts, with tabs through a rear cross
tube and a middle bar, stay in `../rev011-uncut-11T-lowB/` as history.)

### Speakers — two 6.5″ firing up through the deck

**The well is built from parts that are already there.** Its two sides are the rail inner
faces, its floor is the tray, its lid is the deck, and its outer end is the steel cross member.
Only the inner end is new: one 12 mm plywood bulkhead, 172 × 100, that seals the well off from
the batteries. So each speaker costs one bulkhead and one hole in the deck.

| | value |
|---|---|
| Driver | 6.5″, **Ø165 × 50 deep** (owner's, measured) |
| Hole in the lid | **Ø165**, on the centreline, 130.5 and 1175.5 mm from the lid's front edge |
| Well, clear | 181 long × 172 wide × 100 deep |
| Sealed volume | **≈ 2.7 litres** behind each driver |
| Air under the cone | 50 mm |

**The one WARN: the hole edge is 3.5 mm from the rail.** A Ø165 hole in a bay that is 172 mm
wide leaves almost nothing. Most 6.5″ drivers with a Ø165 rim only need a cutout near Ø147,
which would give 12.5 mm. **Measure your driver and set `spk_cut_d`** — the well length, the
bay, the wheelbase and the rail length are all derived from it, so they shrink on their own.

Two more things the model does not draw. The well is only sealed if you actually seal it:
run silicone or foam tape where the plywood meets the steel, or the box leaks and the bass
goes. And the deck is what you stand on, so **each hole needs a grille that takes a foot** —
the lid carries nothing across the hole. The lid still lands on both rails: 68.5 mm of
plywood is left each side of the hole, over a 40 mm rail.

Hide the drivers in any render with `show_speakers = false`.

### Checks — all PASS

| Check | Result |
|---|---|
| front cross member behind the front pod at full steering lock | 17.3 mm |
| rear cross member + lid edge to the rear track, full travel | 26.8 mm |
| rail rear end ahead of the front shock | 8.9 mm |
| rail inner face / M12 weld nut to the track edge | 27 / 11 mm |
| green plate / front shock tab above the spring, full travel | 2.7 / 2.7 mm |
| green plate at the rail end / at the rear bolt hole / at the shock eye hole | 83 / 97 / 21 MPa |
| rail at the joint / rails with rider ×2 | 30 / 30 MPa |
| speaker hole edge to the rail inner face | **3.5 mm — WARN**, see "Speakers" |
| speaker rim to the lid edge / air under the cone | 56 / 50 mm |
| lid beside a speaker hole | 68.5 mm each side, over a 40 mm rail |
| sleeve bearing / sleeve under bolt preload / M12 shear | 77 / 140 / 68 MPa |
| bolt joint | 7684 N per bolt vs 10000 N grip — does not slip |
| plywood lid 12 mm, one foot | 6.5 MPa (limit 15) |

Static spring forces at the travel limits; steel limit 141 MPa (0.6 × 235). The only WARNs
left are the lower shock bolt (below).
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

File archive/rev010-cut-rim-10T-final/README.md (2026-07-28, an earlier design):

# Apollo Track Pod — Articulated "Split-Frame" Suspension Mod

**Rev 010 · 2026-07-26 · FINAL PAIR: (A) Rev 010 — design of record: rim flanges CUT (clean cut confirmed: the hub's 5 fins, 4.1 mm blades, arch to the tunnel floor's UNDERSIDE and never touch the flanges; casing measured Ø123), printed 10T sprocket on the Ø149×20.5 floor — rib 18×15, wheel Ø179, cord Ø191, tooth marks every 56.2 mm on the rib (36°); A = 220.8, carriers 224; +10 % launch vs 11T, margins 8.2/5.0 mm; ALL guards PASS. (B) Rev 009 — no-cut twin (archive/rev009-uncut-11T): 11T on the factory rim, A = 203.5,
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

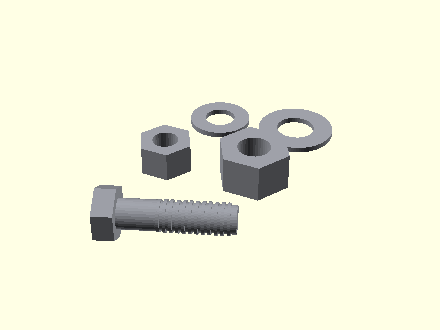
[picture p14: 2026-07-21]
docs/images/thumb_hardware.png

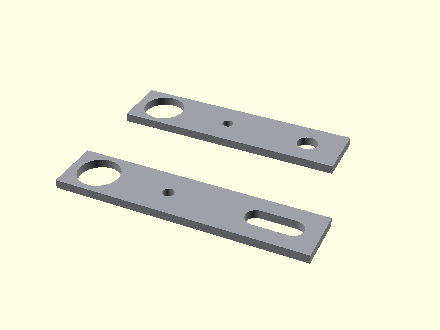
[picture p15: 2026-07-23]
docs/images/thumb_arm_plates.png

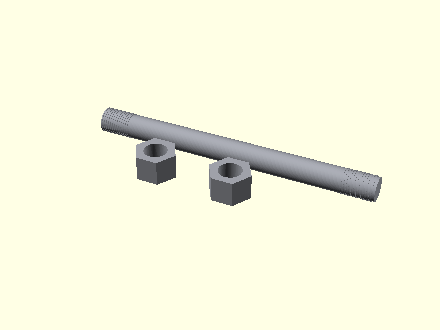
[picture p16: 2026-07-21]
docs/images/thumb_stud_m16.png

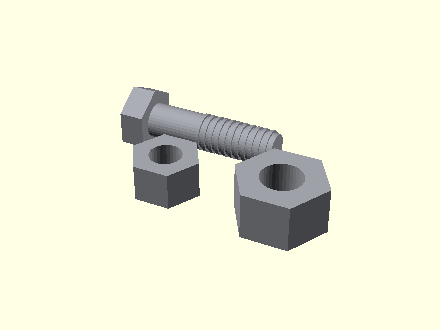
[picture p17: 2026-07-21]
docs/images/thumb_fork_hw.png

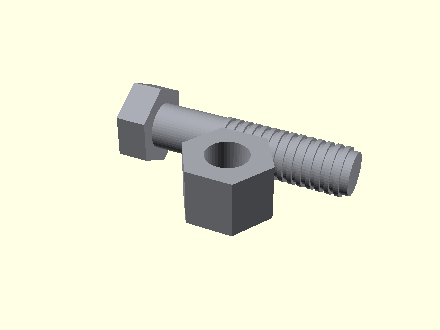
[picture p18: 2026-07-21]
docs/images/thumb_bolt_m8_35.png

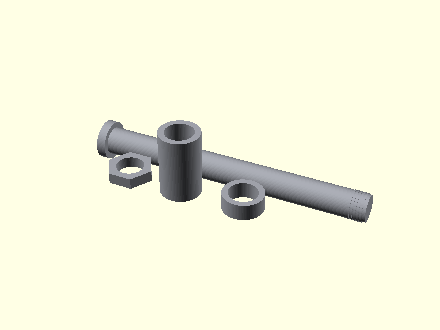
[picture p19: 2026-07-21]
docs/images/thumb_idler_axle.png

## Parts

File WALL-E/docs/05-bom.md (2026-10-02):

# 05 — Bill of materials

Buy in phase order. Est. is **USD**. You pay **shekels**. Compare delivered prices. Israel VAT ~$75 per import — several small orders can beat one big one.

- Stock = ships this week. Long = 4–8 weeks. Order long items first.
- **§9 not here:** fuses, DC contactors, mushroom E-stop. Fake ratings fire.
- Search links last longer than product links. Read §9 before clicking.

---

## 1. Buy now — bench, no frame

**All of §1 and §1b is owned or ordered (2026-09-29).** Controllers already owned (reverse line confirmed). 1b buys back what they do not report.

| Qty | Part | Est. | Lead | Notes | Buy from — **read §9 first** |
|---|---|---|---|---|---|
| 1 | Teensy **4.0** | 38 | **Owned** (2026-09-26) | Spine. **Not 5 V tolerant** — needs the §1b level shifter. | owned |
| 1 | **FlySky FS-i6X** transmitter + **FS-iA6B** receiver, **Mode 2** | 41 | **Ordered 2026-09-26**, ₪151.39 | **This exact pair.** Mode 2: the right stick springs back in both axes, so letting go of it stops the robot. Runs on 4 × AA, not included. The Spine firmware reads **iBus** on Serial1 and knows this receiver's quirk: after the transmitter is switched off it keeps sending the last stick values instead of failing safe, so `RC_FROZEN_MS` treats 500 ms of identical frames as a dead link (safety log test 3). Another brand means rewriting `rc_poll()`. The receiver must be the **iA6B** (it has the iBus servo port), not the iA6. Set the i6X to **10 channels** in its menu: the robot uses 7 (section 6). | [search: FS-i6X FS-iA6B](https://www.aliexpress.com/w/wholesale-flysky-FS-i6X-FS-iA6B.html) |
| 1 | Multimeter with a clamp for **DC** current | 25 | **Owned** (2026-09-29) | The clamp matters. You cannot break into a 40 A circuit to measure it. **Check the listing says DC amps, not only AC.** Most cheap clamp meters are AC-only and will read 0 A on a battery wire. Needs 100 A DC or more. You use it to find the controllers' real current limit, to calibrate the two ACS758 sensors, and to measure contactor coil inrush — see the 167 W warning in §9. | [AliExpress ₪77.35](https://he.aliexpress.com/item/1005002037433118.html) |
| 1 | Bench power supply, 60 V 5 A, adjustable current limit | 69 | **Owned** (2026-09-29) | The current limit turns a wiring mistake into a beep instead of a fire. Borrow one if you can. Priced from a Jesverty 60V05A listing at ₪207.92, about 69 USD, or 61 with the on-page coupon. Two checks before paying: keep the **220 V EU plug** variant selected, and confirm the description says **CC / constant current** — you need the supply to drop its voltage automatically at the limit, not just display the current. 60 V is the minimum useful figure because a full 48 V pack sits at about 54.6 V. | [search: Jesverty 60V05A](https://www.aliexpress.com/w/wholesale-Jesverty-DC-lab-power-supply-60V-5A.html) — Jesverty Official Store, variant `60V05A-Model V`, 220 V EU plug |

Day one: one motor, own controller, hand throttle, on blocks. No code.

---

## 1b. Teensy → scooter controllers — ~$60

Throttle is +5 V, GND, signal (~0.8 V rest, ~4.2 V full). **Measure yours.** DAC fakes it.

| Qty | Part | Est. | Lead | Notes | Buy from — **read §9 first** |
|---|---|---|---|---|---|
| 2 | MCP4725 12-bit I2C DAC breakout | 4 | **Owned** | One per controller. Makes the throttle voltage. Two share one I2C bus at addresses 0x62 and 0x63. | [search](https://www.aliexpress.com/w/wholesale-MCP4725-DAC-module.html) |
| 1 | I2C level shifter, 4 channel (BSS138 or TXS0102) | 2 | **Owned** | The DAC has to run at 5 V to reach full throttle, and **the Teensy is not 5 V tolerant.** Without this you damage its pins. | [search](https://www.aliexpress.com/w/wholesale-BSS138-I2C-level-shifter.html) |
| 4 | Opto-isolator, PC817, plus resistors | 3 | **Owned** | Two per controller: one pulls the **reverse** line, one pulls the **e-brake** line. Isolated, so a controller fault cannot travel back into the Teensy. | [search](https://www.aliexpress.com/w/wholesale-PC817-optocoupler.html) |
| 1 | Watchdog: **NE555** (DIP-8, 10 pcs) plus a **2-channel 5 V relay board, HIGH-level trigger**, optocoupled (Songle SRD-05VDC-SL-C) | 8 | **Owned** (2026-09-29) | **Not optional.** See the warning below. NE555 replaces the TLC555: same pins, runs at 5 V, 100 nF + 10 µF across pins 8–1. One relay per throttle, **COM + NC**. **Set the board jumper to HIGH**: then a dead 555 or a broken IN wire drops the relay and shorts the throttle. On LOW trigger the same fault leaves the throttle live. Silver contacts on a mA signal: keep the board in the sealed box and run safety tests 15–16 every morning. | [search](https://www.aliexpress.com/w/wholesale-TLC555-timer-IC.html) |
| 2 | ACS758 100 A bidirectional hall current sensor | 18 | **Owned** | Gives the Teensy a current reading the controllers do not report. One per pack lead. | [search](https://www.aliexpress.com/w/wholesale-ACS758-100A.html) |
| — | Resistors for the motor thermistor divider: **2 × 10 kΩ** to 3.3 V (`NTC_FIXED`) | 2 | **Owned** (kit) | Reads the hub motor's **own** temperature sensor straight into the Teensy. This is the defence against risk R5, and it replaces arbitration rule 9's data source. | [search](https://www.aliexpress.com/w/wholesale-metal-film-resistor-kit.html) |
| — | Resistors for two pack voltage dividers: **200 kΩ top + 10 kΩ bottom** each, ÷21 (`VOLT_SCALE`), 60 V → 2.86 V | 2 | **Owned** (kit) | Arbitration rules 5 and 11 need pack voltage, and the controllers do not report it, so the Teensy measures it. Mind the ground reference. | [search](https://www.aliexpress.com/w/wholesale-metal-film-resistor-kit.html) |
| — | Wiring to bring both motors' hall sensors to the Teensy | 6 | **Owned** (cable C, §2) | Arbitration rule 4 asks "is each track alive?" and the controllers do not answer, so the Teensy counts hall edges: commanded to move, halls not changing, track is dead. | [search](https://www.aliexpress.com/w/wholesale-shielded-cable-4-core.html) |
| — | Shielded 4-core signal cable and connectors | 15 | **Owned** (cable C, §2) | Throttle lines run beside motor phase wires. Shield them or the robot twitches. | [search](https://www.aliexpress.com/w/wholesale-shielded-cable-4-core.html) |

- No PWM “analogue”. DAC only.
- DAC holds last voltage. Hardware watchdog (NC relay) shorts throttle when kicks stop.
- E-stop also into controller **e-brake**.
- ACS758 output is 5 V: **10 kΩ + 10 kΩ divider** (÷2, `ACS_DIV_RATIO`) into each Teensy pin, 4 resistors. Owned (kit).
- 100 nF from each analogue pin to GND. Owned.
- Bought back: thermistor, ACS758. Not bought: FOC, tunable limits, full-speed reverse.
- If the controller has cruise that cannot turn off, it does not go on this robot.

---

## 2. Frame and drive — phase 1

| Qty | Part | Est. | Lead | Notes | Buy from — **read §9 first** |
|---|---|---|---|---|---|
| 2 | DC contactor, **48 V coil** (confirmed 2026-09-17), **DC rated**, 1NO: **ZJ50A** (or ZJ100A) | 80 | **Owned / ordered** (2026-09-29) | Chat decision (PROGRESS.md). Not CJX2-K (coil-only / AC listing). **An AC-rated relay will weld shut.** `04-power-and-wiring.md` section 5. | **§9 — not here** |
| 1 + 1 | **48 V fuses: EARU 10×38 gPV 1000 V DC, 2-pole holder with lamp (EAFSH-1038PV-L-B-2P)** — one **30 A** kit (pole A = pack A, pole B = pack B) and one **10 A** kit (pole 1 = amplifier 10 A, pole 2 = coil chain **6 A**). Loose fuses: 30 A × 1, 6 A × 3. | 25 | **Owned / ordered** (2026-09-29) | Main fuse 30 A (owner, 2026-09-29: 40 → 30 A): matches the XT60 and protects the 12 AWG wire; 40 A bursts of seconds pass, a minute of stall does not — that is the motors overloaded, not a reason for a bigger fuse. Coil chain **6 A** (no 5 A in this range): sized for the coil inrush, not the 0.3 A hold — measure the inrush on the bench supply. The second 10 A from the kit is the spare. The lamp lights when a fuse has blown. The two poles are not joined inside, but **label them A / B / AMP 10A / COIL 6A**. **Anything on the 48 V side must be rated ≥ 58 V DC; blade and J-case fuses are 32 V.** Plus ~20 cm of 35 mm DIN rail. EARU **official store only** — the one exception to the no-AliExpress-fuses rule. | EARU Official Store (AliExpress) |
| 3 + 3 m | **A — 12 AWG silicone**, red + black | 20 | **Owned** (2026-09-29) | Pack → fuse → contactor → controller, the ground bond, 12 V pack → rail. **Three wire sizes only (owner, 2026-09-29):** 12 AWG is the thickest, it replaces 10 and 14. | owned |
| 4 + 4 m | **B — 16 AWG silicone**, red + black | 15 | **Owned** | 12 V loads, amplifier supply, contactor coils and the E-stop chain (replaces 20 AWG). | owned |
| 4 m | **C — 22 AWG shielded, 4-core** | 10 | **Owned** | Throttle / reverse / e-brake, halls, motor thermistors. HDMI cable is acceptable for the hall and thermistor runs only, not the throttle. | owned |
| — | Motor phase cable | — | **Owned** | Special cord, already bought. | owned |
| 1 set | Crimp set: **HS-30J** ratchet tool (22–10 AWG) + 102 pcs insulated ring kit + **RV5.5-8 × 20** + **RV5.5-6 × 10** + 328 pcs heatshrink kit | 40 | **Owned** (2026-09-29) | The tool is not optional. See `04-power-and-wiring.md` section 8. 16 AWG → red: RV1.25-3 × 2 (E-stop), RV1.25-4 × 8 (coils, 5 A and 10 A fuses), RV1.25-5 × 6 (12 V distribution) — the kit covers these. 12 AWG → yellow: RV5.5-8 × 11 (fuses, contactor studs, ground bond), RV5.5-6 × 8 (controllers, 12 V pack) — the kit has 2 + 5, hence the extra bags. Hole sizes are guesses until the fuses and contactors arrive. Screw-terminal boards take bare wire. Dupont connectors owned. | [search](https://www.aliexpress.com/w/wholesale-hydraulic-crimping-tool-cable-lug.html) |
| 4 | **XT60** connector pairs | — | **Owned** | The main disconnect on each pack, plus two spares. **Was XT90-S; owner uses XT60 (2026-09-29).** XT60 has **no anti-spark resistor**, so **plug and unplug only with the contactors open** (disarmed) — then the controller capacitors are not on the pack side and nothing sparks. Soldered, 12 AWG fits. **Put the SOCKET half on the battery** — the disconnect sits ahead of the fuses, so exposed pins on the pack side would be an unfused short waiting for a dropped spanner. See `04-power-and-wiring.md` §5. | owned |
| 5 pairs | Silicone caps for the XT60 halves | 6 | **Owned** (2026-09-29) | 4 needed: both halves of the 2 main disconnects. Dust cover and idiot guard in one. Anderson housings were genderless and recessed; XT is not, so this replaces a safety property we gave up. | [search](https://www.aliexpress.com/w/wholesale-XT60-connector-silicone-cap.html) |
| 1 | Latching mushroom emergency stop, red, IP65 | 25 | **Owned / ordered** (2026-09-29) | Normally-closed contact. Meter test before fitting: NC beeps, push, beep stops and stays stopped, twist, beep returns. 20 times. | **§9 — not here** |
| 3 (+1) | **Manual off switch per battery** (owner, 2026-09-30; decide at the end): rotary "battery isolator" **12–60 V DC**, 100 A, red knob, + a 12 mm red panel LED each (**48 V** LED for packs A and B, **12 V** LED for the 12 V pack) | 25 | Open | After each battery's fuse: pack → XT60 → fuse → switch → contactor (12 V: → rail). **Turn off only when disarmed** (contactors open): then no arc. Not an E-stop. A normal lighted car switch is not rated for 48 V DC and its LED is 12 V. Check: seller with real sales, **M8** studs (our RV5.5-8 lugs), removable knob. | [search: battery isolator switch 60V DC](https://www.aliexpress.com/w/wholesale-battery-isolator-switch-60V-DC.html) |
| 1 | **12 V 20 Ah LiFePO4 battery** — the electronics supply | 75 | Stock | Owner decision D8. **Different case from the 48 V packs:** this one is **181 × 167 × 77 mm**, those are **400 × 110 × 80 mm** and live in the frame box. 240 Wh against a 20 W rail is 12 hours. This rail is the Teensy, the Face, the fans, and the powered USB hub. **The XPS is not on it.** **Fit LYING ON ITS SIDE on the lower deck**, on a strap, not glue. Upright it is 167 mm tall and it lifts the laptop tray — `cad/walle_frame.scad` guards this. Unplug the XT60 and lift it out after the laptop tray comes off (L17). | [search](https://www.aliexpress.com/w/wholesale-12V-20Ah-LiFePO4-battery.html) |
| 1 | LiFePO4 charger, 14.6 V 5 A | 25 | Stock | For the battery above. Many battery listings offer this charger as an option: buy both in one order. **A lead-acid charger is not a LiFePO4 charger** — the float voltage is wrong and it will sit there cooking the pack. | [search](https://www.aliexpress.com/w/wholesale-14.6V-5A-LiFePO4-charger.html) |
| 2 | Fuse, 15 A, **ATO blade** (1 + 1 spare), and a waterproof inline ATO holder for 12 AWG, at the battery terminal | 5 | **Owned / ordered** (2026-09-29) | 12 V side, so a 32 V blade fuse is fine here. A 20 Ah LiFePO4 will push hundreds of amps into a short and its BMS is not a fuse. Mount it **at the terminal**, not at the far end of the run. | owned |
| 1 | Buck converter, **48→24 V, 5 A (120 W)**, sealed aluminium, input **48V60V (30–75 V)** | 9 | **Ordered 2026-09-29**, ₪31.61 | The amplifier's supply only (owner, 2026-09-29: was 48→32 V for the TPA3255). Pick the **30–75 V** input variant, not 30–60 V: a full pack is 54.6 V. `04-power-and-wiring.md` section 4. | [search](https://www.aliexpress.com/w/wholesale-48V-to-24V-5A-step-down-converter.html) |
| 2 | Buck converter, 12→5 V: **RCNUN 12V/24V → 5 V 10 A**, IP67 sealed (1 + 1 spare, §8) | 12 | **Ordered 2026-09-29**, ₪18.98 each | Teensy, both ESP32 eyes, the watchdog, DACs and ToF ring: ~1.5 A, so 10 A runs cool. If it dies the Spine and both eyes go dark together, hence the spare. Not the USB hub (own supply from the 12 V rail). | RCNUN Official Store |
| — | Capacitors: 4700 µF 25 V (12 V rail), 10 µF and ~1 µF (NE555), 100 nF (analogue pins) — **owned** (2026-09-29). **TVS: 10 × 5KP58A and 10 × 5KP64A**, both **ordered 2026-09-29**: fit the 58A for 13S packs (charger 54.6 V), the 64A for 16S LiFePO4 (charger 58.4 V). | 20 | Ordered | Rail buffer and controller input protection. One TVS across each controller's 48 V input, legs short, **band (cathode) to +48 V**, other end to −; backwards it is a short and the fuse blows. 5KP58A stays off to 58 V: right for **13S (54.6 V full)**. On **16S LiFePO4 (58.4 V full)** a full pack sits over that, so use the **5KP64A** (off to 64 V). Pack type still to confirm from the charger label. | [search](https://www.aliexpress.com/w/wholesale-capacitor-4700uF-25V.html) |
| — | Steel box tube 60×30×3 and 30×30, 60×6 flat, 6 mm plate | — | — | **You already have the steel.** Cut list is echoed by `cad/walle_frame.scad`: 2 × 550 rails, 2 × 251 cross members (1602 mm of 60×30), 2 hangers 60×6, 215 mm, 2 tabs 80 × 177 and 4 clamp plates 80 × 30 from 6 mm plate. The frame hangs from the pods' U braces (2026-09-29). | owned |
| — | Pod joint bolts: **2 × M12×40 8.8** (replace the U braces' inboard M12×35) and **8 × M10×35 8.8**, all with washers and nylocks | 10 | Stock | Per pod: 1 M12 + 4 M10. No sleeves, no packers: the rails have no bolt holes now. | local hardware store |
| 12 mm | Birch plywood sheet | 60 | Stock | Battery box (six panels), electronics shelf, and the lift-out laptop tray (315 × 360). | timber yard |
| 2 | Castor wheels, Ø75 | 35 | Stock | Anti-tip. `cad/walle_frame.scad`. Mounting steel you already have. | [search](https://www.aliexpress.com/w/wholesale-caster-wheel-75mm.html) |

### Sealing the battery box — small money, and it decides whether the packs survive

The box hangs inboard of the belts, which throw sand at it. `06-why-the-batteries-are-low.md`
has the reasoning. Cheap parts, so buy spares of all of them.

| Qty | Part | Cost, USD | Lead | Notes | Buy from |
|---|---|---|---|---|---|
| 5 m | Closed-cell foam tape, 3 mm, self-adhesive | 10 | Stock | The lid gasket. EPDM, not open-cell — open-cell soaks up water and holds grit. | [search](https://www.aliexpress.com/w/wholesale-EPDM-foam-tape-3mm.html) |
| 1 sheet | Closed-cell foam, 8 mm | 10 | Stock | The pad on top of the packs. Clamps them down and takes the vibration. | [search](https://www.aliexpress.com/w/wholesale-closed-cell-foam-sheet-8mm.html) |
| 0 | Screw-in membrane vent, M12, IP67 (Gore type or equivalent) | 0 | **Skipped** (owner, 2026-09-30) | **Not buying.** Packs are sealed on their own and plywood breathes a little anyway. Instead: seal the lid well and check for dust inside the box once during the festival. Was: 1 in the **lid**. A sealed box breathes with the day/night temperature swing; this is the clean path so it does not pull dust through a leak. | [search](https://www.aliexpress.com/w/wholesale-M12-waterproof-breather-vent.html) |
| 4 | Cable gland, M16, IP68 | 10 | Stock | Charge leads and pack sense wiring out of the box. Not a drilled hole. **The gland holds a jumper, not the pack.** Each traction pack unplugs inside the box (XT60 plus a charge pigtail) so the pack lifts out. | [search](https://www.aliexpress.com/w/wholesale-cable-gland-M16-IP68.html) |
| 16 | M5 bolts, nuts and washers, 25 mm | 8 | Stock | 12 for the lid at 110 mm pitch, plus spares. A gasket only seals where it is squeezed. | [search](https://www.aliexpress.com/w/wholesale-M5-bolt-nut-washer-set.html) |
| 3 | **XT60** charge connector with a dust cap, body-mounted | 18 | Stock | One per traction pack, plus one for the electronics battery. **Daily charge is in place.** Each pack also has the mating half on the pack itself, so you can unplug and charge it on a bench. **Label all three.** Two are 48 V and one is 12 V, and the connectors are identical. | [search](https://www.aliexpress.com/w/wholesale-XT60-panel-mount-connector.html) |
| 4 | M8 bolts, body floor into the risers | 8 | Stock | The body lifts off so the 48 V box lid can open. Do not weld the body to the risers. | [search](https://www.aliexpress.com/w/wholesale-M8-bolt.html) |
| 3 | Webbing strap or Velcro, 25 mm | 8 | Stock | One each for the 12 V pack, the PD pack, and a spare. Clamps them to the lower deck. Not glue. | [search](https://www.aliexpress.com/w/wholesale-25mm-webbing-strap.html) |

### The contactor is the long pole

Two DC-rated contactors is the single biggest line in this section and the one most likely to
arrive late. Order them in phase 0 even though they are not needed until phase 2.

---

## 3. Compute and sensors — phase 2, not before

Brain = owned XPS 15 9510 (L25). No internet. Two floors (L26). Camera ordered (L27).

| Qty | Part | Est. | Lead | Notes | Buy from — **read §9 first** |
|---|---|---|---|---|---|
| 2 | Body fans: **Gdstime 12025 IP67, 12 V, dual ball, 2500 RPM**, 2-wire + 120 mm filter/grille set (2) + PC filter sheet 500×400 (3/5 mm, cut 12 pads) + **4 × D4184 MOSFET module** | 25 | **Bought 2026-10-02** | 1 intake (filtered, low on the back, away from the tracks) + passive vent high on the other side; the 2nd fan is the spare or a slow exhaust later (intake must stay ≥ exhaust: positive pressure, or dust comes in through the gaps). Teensy PWM (100–500 Hz, kick-start 1 s at 100 %, never under ~40 %) through a D4184 on the fan minus; the laptop sends the speed from its CPU/GPU temperature. ~3 W full, ~0.8 W at 60 %. D4184s also for the chest screen. Swap/wash filter pads every 1–2 days. | [search](https://www.aliexpress.com/w/wholesale-120mm-12V-fan-filter.html) |
| 1 | Powered USB hub: **ASOMETECH 7-port USB 3.0, 12 V adapter**, metal, switch per port, USB-C adapter included | 25 | **Ordered 2026-09-30**, ₪76.22 | 7 ports = 7 devices, no spare port (mic goes straight into the XPS). Power: a **DC barrel pigtail** (check size, usually 5.5 × 2.1) from the 12 V rail with a **3 A fuse**; keep the adapter whole for the bench. **Meter the polarity first** (usually centre +). No screw holes: strap or printed clip; tape the upstream cable and C adapter. The XPS has USB-C only. Webcam, LiDAR, Teensy, both Face boards and the mic share this hub. **Power the hub from the 12 V rail**, not from the laptop. | [search](https://www.aliexpress.com/w/wholesale-powered-USB-C-hub-USB3.html) |
| 1 | USB-C PD power bank, 20 000 mAh, **65 W or more** | 40 | Stock | Feeds the XPS. Check the label says 65 W PD, not 22.5 W. Strap it on the **lower** deck, not on the laptop tray. Keep it off the laptop vents. Pull it if it gets hot. **Open (owner, 2026-09-30; decide at the end of the BOM):** instead, charge the XPS from the 12 V battery: battery → 10 A fuse → **12 V → USB-C PD 65 W converter** (hard-wired, not a lighter plug) → XPS. ~5–6 A from 12 V. A 20 Ah battery then lasts only ~3–3.5 h: options are a **12 V 50 Ah** battery (~8 h, check it fits the lower deck), swap/charge at midday, or a 48 V → USB-C PD converter from a drive pack. | local / [search](https://www.aliexpress.com/w/wholesale-20000mAh-65W-PD-power-bank.html) |
| 1 | ELP-USB1080P03-KLC1100, metal cube, LC1100 lens | 52 | Ordered 2026-09-23 | **L27.** 1080p 30 fps, SC2210, USB 2.0 UVC, 5 V 180 mA, 3 m cable. **42 × 42 × 36 mm**. LC1100 **86°**. ₪195.65. | owned |
| 1 | **WitMotion COIN-D6** dToF LiDAR, 12 m, 360° (was RPLIDAR A1M8) | 44 | Stock | Only needed for **ASSIST** (WALL-E driving himself); MANUAL does not use it. dToF, **60 klx** sunlight rating (the A1M8 is triangulation and weak in sun), brushless, IPX4, Class 1 eye-safe. 0.05–12 m, 0.9°, 10 Hz, 4000 pts/s. 5 V 240 mA (800 mA start), 3.3 V UART 230400 with a USB adapter in the box. Operating to **50 °C**: shade it. Protocol PDF, spec sheet and ROS drivers (source) are in the seller's [Drive folder](https://drive.google.com/drive/folders/1_XfZTemyIBoZssQmFW5Jx17jxx3hn337): start `AA 55 F0 0F`, stop `AA 55 F5 0A`, `0x55AA` packets, angle correction in the driver. `perception.py` `_lidar_loop` is still a TODO. | AliExpress ₪163.98, WitMotion, "D6 Lidar" |
| 6 | VL53L1X time-of-flight sensor: **TOF400C-VL53L1X** module (4 m, with black cover) | 23 | **Bought 2026-10-02**, ₪13.20 each | The bumper ring: **5 on the robot (3 front: left, centre, right with the corners ~30° out; 2 back) + 1 spare** (owner, 2026-10-02; was 6). These wire to the **Spine**, not the Brain. Height ~30–40 cm. Check the label says **TOF400C** (the listing photos show TOF200C = VL53L0X). Dust: keep the cover, wipe daily, crosstalk-calibrate with the cover on; firmware flags a sensor that reads short for long ("dirty"). Firmware: `TOF_COUNT` 6 → 5, `TOF_FWD` 3, `TOF_AFT` 2. | [search](https://www.aliexpress.com/w/wholesale-VL53L1X-module.html) |
| 2 | I2C multiplexer (TCA9548A), 1 + 1 spare | 5 | **Bought 2026-10-02** | Six VL53L1X boards share one I2C address. You need this or you need to sequence their XSHUT pins. | [search](https://www.aliexpress.com/w/wholesale-TCA9548A-I2C-multiplexer.html) |
| 1 | **GY-BNO085** IMU board, 9-axis fused | 12 | **Ordered 2026-09-28**, ₪44.90 | Pitch for tip safety (ASSIST is refused without it: robot tips forward at 19.4°, castor catches at 9.9°, stop forward above ~7°) and a heading. Wired as **UART-RVC**: **PS0 → 3V3, PS1 → GND**, set before power-up; then **SDA is TX**, 115200 baud, 19-byte packets `AA AA` at 100 Hz with yaw/pitch/roll in 0.01°. Power from 3V3, not 5 V. Only SDA → adapter RXD is needed. Mount flat on the frame, away from the hub motors and power cables (the compass reads their magnets; pitch does not care). | ordered |
| 5 | USB-TTL adapter, **CP2102** (5-pin: 3V3, TXD, RXD, GND, +5V) | 9 | **Bought**: 1 earlier + 4 on 2026-10-01 (₪6.44 each) | 1 for the BNO085 IMU, 1 per eye, 2 spare. Eye: CP2102 TXD → eye RXD, RXD → eye TXD, GND → GND; leave the CP2102 +5V and 3V3 empty (eye power from the RCNUN 5 V). CP2102 is 3.3 V logic. Not PL2303 (fakes, Windows blocks them). | bought |
| 1 | GPS: **Waveshare ESP32-S3-Touch-AMOLED-1.75-G** (GPS version, LC76G) — one eye board doubles as the GPS | 35 | **Bought 2026-10-01** (~₪124) | **Replaces the u-blox NEO-M9N** (owner, 2026-10-01). Midburn is a flat featureless plain: GPS, not SLAM. LC76G → ESP32 on IO17/IO18 (do not use those header pins for anything else); the eye firmware forwards NMEA to the laptop on its TXD/RXD link. The included ceramic antenna plugs into the **IPEX 1 (u.FL)** socket next to the USB-C: unplug it, unscrew it, keep it for bench tests. The steel tube blocks GPS, so the antenna goes outside (rows below). The 2 standard boards: one eye + one spare. | Waveshare / TOP1 store |
| 1 lot (5) | Pigtail **IPEX (u.FL) → SMA female**, 1.13 mm, **20 cm** | 3 | **Bought 2026-10-01** (₪11.36) | Board GPS socket → SMA nut in the head wall. Plug the u.FL once; do not pull it; drop of hot glue on the cable. | AliExpress |
| 1 | **GPS active antenna: QUESCAN 30 dB, SMA male (SMA-J)**, GPS/GLONASS/Galileo/BeiDou, 15 cm cable | 6 | **Bought 2026-10-01** (₪16.49) | **Bare patch, not waterproof:** under the head top cover (dry plywood/plastic; not steel), white square up. SMA socket high in the head so 15 cm reaches; if short, add an SMA male→female RG174 extension 0.5–1 m. **SMA male, not RP-SMA.** Active 3–5 V: the LC76G powers it through the cable. Test outside before the festival (first fix 1–2 min). | [search](https://www.aliexpress.com/w/wholesale-GPS-active-antenna-SMA-male-waterproof.html) |
| 1 pack + 5 m | **Dupont jumpers male-female**, 20–30 cm, and **4-core shielded cable 24 AWG** | 8 | Stock | The eye header is **female** (holes): male end into the eye, female onto the CP2102 / RCNUN lead. 4 wires per eye: VBUS, GND, TXD, RXD. Fix plugs with hot glue against vibration. | AliExpress |
| 1 | Microphone: **BOYA BY-MM1** cardioid shotgun (3.5 mm, furry windshield) + **USB-C sound card** | 26 | **Ordered 2026-09-30**, ₪87.99 + ₪7.73 | Laptop mic is inside the body: this goes up front, high, pointing at people's mouths, above the speakers. Mic → sound card mic input (TRS cable, 3 rings, not the coiled phone cable) → USB. Sound card has a **USB-C plug**: fits the XPS, or the hub only with a USB-C port or a C → A adapter. Cheap card: test the mic's plug-in power level; backup Vention USB sound card ₪19. Set WALL-E to this input when it arrives. | ordered |

---
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

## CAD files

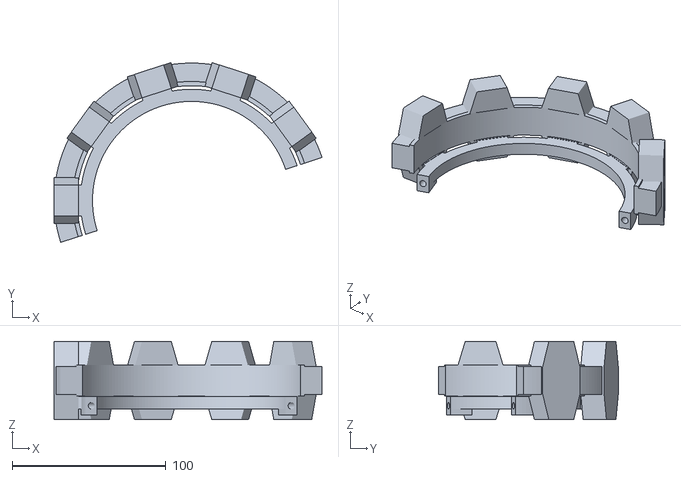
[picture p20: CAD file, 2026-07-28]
stl/rev010_half_A.stl
174.6 x 117.0 x 51.0

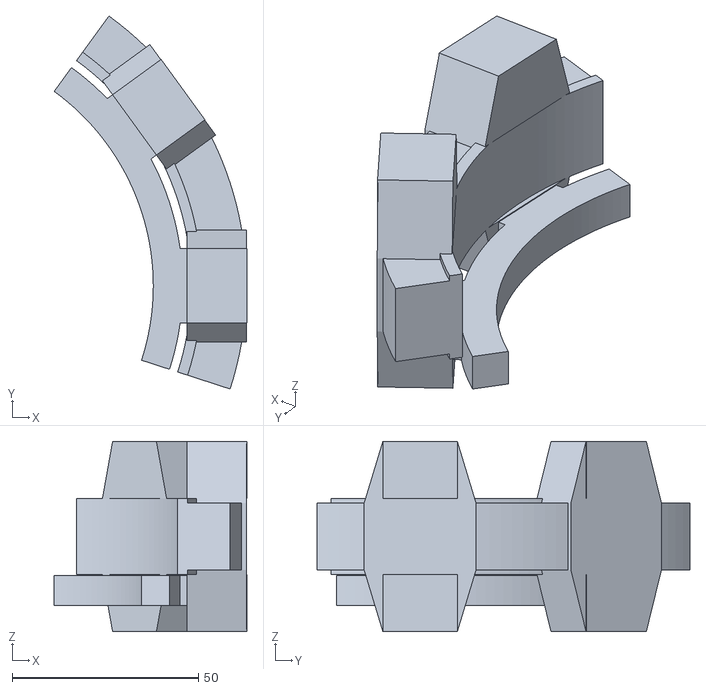
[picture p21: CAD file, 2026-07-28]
stl/rev010_test_arc.stl
51.7 x 100.1 x 51.0

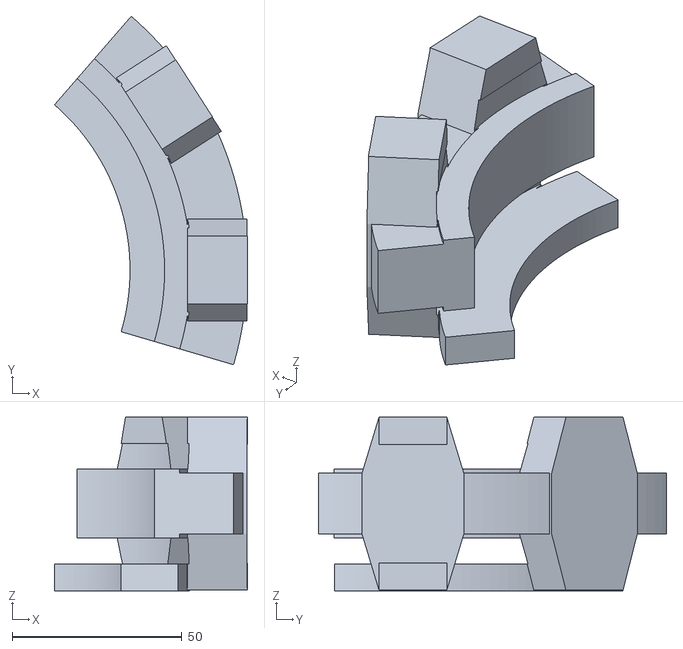
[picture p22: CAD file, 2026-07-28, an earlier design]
archive/rev013-double-shear/stl/rev011_test_arc.stl
56.9 x 102.7 x 51.2

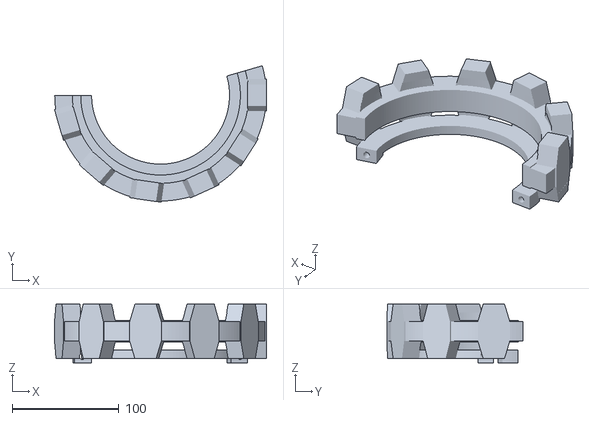
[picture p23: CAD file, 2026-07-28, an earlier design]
archive/rev013-double-shear/stl/rev011_half_B.stl
198.4 x 127.7 x 55.2

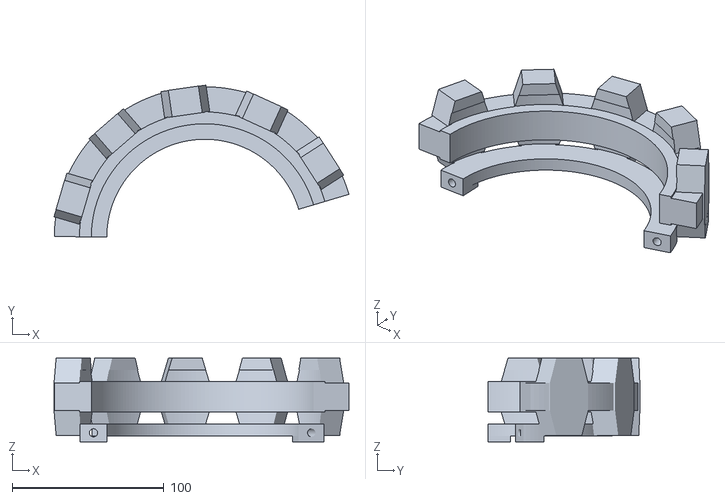
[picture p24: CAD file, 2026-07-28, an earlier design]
archive/rev013-double-shear/stl/rev011_half_A.stl
194.2 x 99.9 x 55.2

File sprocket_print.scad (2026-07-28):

// ============================================================================
//  APOLLO TRACK POD — PRINT-READY DRIVE SPROCKET (wheel-hub clamp shells)
//  Companion to apollo_track_pod.scad — generates the actual 3D-printable
//  part for BOTH final revisions:
//
//    rev = 10  (design of record, archive/rev010-cut-rim-10T-final):
//              10T on the CUT rim — flange walls ground off, the print is a
//              3 mm clamp shell around the bare Ø149 x 20.5 tunnel floor,
//              rib 18 x 15 (top Ø179), 10 T-teeth, cord Ø191.
//    rev = 9   (no-cut twin, archive/rev009-uncut-11T):
//              11T on the FACTORY rim — the print FILLS the tire well
//              (Ø149 floor x 20.5, flush to the Ø165 rim body), rib 18 x
//              16.5 (top Ø198.1), 11 T-teeth, cord Ø210.1.
//
//  WHAT THIS FILE ADDS over the assembly model (which draws rib+teeth only):
//   - the clamp shell / well fill that actually grips the drum
//   - the split into two HALF-SHELLS (the uncut Rev 9 rim flanges make a
//     one-piece ring impossible to install; Rev 10 needs the clamp force)
//   - an under-floor bolt ring on the NON-FIN side (the hub's 5 fins arch
//     on the brake-disc side only): the halves bolt to each other through
//     the open space between the fins, per the blueprint's clamp concept.
//     Ring stays inside the lug-tip sweep (Ø149 rev10 / Ø168.1 rev9) and
//     3 mm clear of the Ø123 motor casing — see guard echoes each render.
//   - bore fit clearance (bore_clr) — calibrate with the TEST ARC first
//
//  PIECES (set `piece`, or use the CLI lines below):
//    half_A / half_B  the two bolt-together halves (print axis-vertical)
//    test_arc         2-tooth arc (README pre-print check: bore fit on the
//                     drum + tooth spacing 56.2 mm rev10 / 56.6 mm rev9)
//    both             both halves, exploded 6 mm — visual check only
//
//  CLI EXPORTS (from this folder):
//    for r in 9 10; do for p in half_A half_B test_arc; do
//      openscad -o stl/rev0${r}_${p}.stl -D "rev=${r}" -D "piece=\"${p}\"" sprocket_print.scad
//    done; done
//
//  HARDWARE: rev10 — 2x M4x30 cl.8.8 + nyloc + washers (one per joint line)
//            rev9  — 2x M5x35 cl.8.8 + nyloc + washers
//
//  BEFORE PRINTING (from the rev010 README, still mandatory):
//   - Rev 10: verify floor >= 20 wide and ring wall >= 3 -> grind -> tape
//     circumference must read 468 mm (= Ø149). Send the number first.
//   - Both: print the TEST ARC first; adjust bore_clr until it seats snug.
//   - fin positions are 72.0 deg NOMINAL — verify the bolt bosses (at the
//     split lines) land between fins before committing plastic.
// ============================================================================

rev   = 10;        // [9, 10]
piece = "half_A";  // [half_A, half_B, test_arc, both]

bore_clr = 0.2;    // radial fit clearance on the Ø149 drum seat, per side —
                   // TUNE WITH THE TEST ARC (ABS shrinks ~0.3-0.8%)
joint_gap = 0.25;  // deg trimmed off each half at the split faces (~0.32 mm
                   // at the bore) so the bolts can actually clamp the drum

/* [Shared belt / hub datums — LOCKED, from the rev models] */
belt_pitch = 60;   // belt link pitch
T          = 12;   // belt carcass thickness
lug_h      = 15;   // belt pyramid lug height (tips sweep rib_top - 2*lug_h)
rib_w      = 18;   // centre rib width — rides the 22 mm gap between lug pairs
tooth_t    = 20;   // tooth thickness, circumferential
tooth_span = 51;   // T-tooth width across the belt
tooth_fil  = 5;    // root widening over the rib zone (printed fatigue fillet)
shell_t    = 3;    // clamp-shell skin thickness (rev 10)
casing_d   = 123;  // motor casing OD — MEASURED 2026-07-25
floor_d    = 149;  // factory tunnel-floor Ø (tape check 468 mm)
floor_w    = 20.5; // tunnel-floor width

/* [Per-rev derived] */
teeth    = (rev == 10) ? 10   : 11;
drum_od  = (rev == 10) ? 149  : 165;   // rev10: cut floor; rev9: uncut rim body
drum_w   = (rev == 10) ? 20.5 : 35;    // blade inner faces sit beside this
rim_face = drum_w/2;                   // rim side face |z|
rib_h    = (teeth*belt_pitch/PI - T - drum_od)/2;
rib_top  = drum_od + 2*rib_h;          // belt face Ø (179.0 / 198.1)
blade_r  = drum_od/2 + rib_h - lug_h;  // tooth blade root radius beside the rim
lug_tip_d = rib_top - 2*lug_h;         // belt lug tips sweep this Ø beside teeth

// under-floor bolt ring (non-fin side, -z): between motor casing and lug sweep
ring_in_r  = casing_d/2 + 3;                       // 64.5 -> Ø129 core clearance
ring_out_r = (rev == 10) ? 72.4 : 82;              // Ø144.8 / Ø164 — >=2 mm
                                                   // under the lug-tip sweep
ring_th    = 8;
ring_z0    = -(rim_face + 0.2);                    // registers on the rim face
boss_th    = 12;
bolt_d     = (rev == 10) ? 4.4 : 5.4;              // M4 / M5 clearance
joints     = (rev == 10) ? [18, 198]               // 10T: gaps opposite -> straight split
                         : [180/11, 180];          // 11T (odd): bent split, both
                                                   // lines still through tooth gaps
// rev9 well-fill only: flange pocket cut (steel well walls Ø149->Ø165, 7.25
// wide each side) with 0.4 radial / 0.1 axial clearance
flange_pocket_d = 165.8;

$fa = 2; $fs = 0.4;

// ------------------------------------------------------------------ guards --
echo(str("REV ", rev, ": ", teeth, "T, rib_h ", rib_h, ", belt face Ø", rib_top,
         ", cord Ø", teeth*belt_pitch/PI, ", tooth marks every ",
         PI*rib_top/teeth, " mm (", 360/teeth, " deg)"));
echo(str("GUARD ring-to-lug-sweep: ring OD ", 2*ring_out_r, " vs lug tips Ø",
         lug_tip_d, " -> ", (lug_tip_d - 2*ring_out_r)/2, " mm/side ",
         lug_tip_d - 2*ring_out_r >= 2 ? "PASS" : "FAIL"));
echo(str("GUARD ring-to-casing: ring ID ", 2*ring_in_r, " vs casing Ø", casing_d,
         " -> ", ring_in_r - casing_d/2, " mm ",
         ring_in_r - casing_d/2 >= 2.5 ? "PASS" : "FAIL"));

// -------------------------------------------------------------- primitives --
module wedge(a0, a1){                   // solid pie a0..a1 deg, oversized
  n = max(4, ceil((a1 - a0)/4));
  linear_extrude(height=140, center=true)
    polygon(concat([[0,0]],
      [for (i=[0:n]) 200*[cos(a0 + (a1-a0)*i/n), sin(a0 + (a1-a0)*i/n)]]));
}

module tooth(){                         // identical to the rev models' geometry
  ts = tooth_span/2;  rw = rib_w/2;  t2 = tooth_t/2;  f = tooth_fil;
  translate([drum_od/2 - 1, 0, 0]) rotate([0,90,0])
    linear_extrude(height=rib_h + 1)
      polygon([[-ts,-t2],[-rw,-t2-f],[rw,-t2-f],[ts,-t2],
               [ts, t2],[ rw, t2+f],[-rw, t2+f],[-ts, t2]]);
  for (sd=[1,-1]) translate([blade_r, 0, 0]) rotate([0,90,0])
    linear_extrude(height=lug_h + 0.1)
      polygon([[sd*rim_face, -t2],[sd*ts, -t2],[sd*ts, t2],[sd*rim_face, t2]]);
}

// under-floor ring + per-joint bolt bosses (trimmed to ring_out_r so nothing
// pokes into the belt-lug sweep between tooth stations)
module under_ring(with_bosses=true){
  conn_bot = max(ring_z0 - ring_th, -(tooth_span/2 - 0.1));
  intersection(){
    union(){
      translate([0,0, ring_z0 - ring_th])
        cylinder(h=ring_th, r=ring_out_r);
      if (with_bosses) for (a=joints) rotate([0,0,a])
        translate([(ring_in_r + ring_out_r)/2, 0, ring_z0 - boss_th/2])
          cube([ring_out_r - ring_in_r, 30, boss_th], center=true);
    }
    cylinder(h=400, r=ring_out_r, center=true);
  }
  // connectors: tie the ring into each tooth's outboard blade (-z side)
  for (i=[0:teeth-1]) rotate([0,0,i*360/teeth])
    translate([(ring_in_r + blade_r + 1.5)/2, 0, (ring_z0 + conn_bot)/2])
      cube([blade_r + 1.5 - ring_in_r, tooth_t, ring_z0 - conn_bot], center=true);
}

module sprocket_solid(with_bosses=true){
  difference(){
    union(){
      // shell (rev10) / well fill flush to the rim body (rev9)
      cylinder(h=floor_w, d=(rev == 10) ? drum_od + 2*shell_t : drum_od,
               center=true);
      cylinder(h=rib_w, d=rib_top, center=true);            // centre rib
      for (i=[0:teeth-1]) rotate([0,0,i*360/teeth]) tooth();
      under_ring(with_bosses);
    }
    // drum seat: the Ø149 floor + fit clearance
    cylinder(h=floor_w + ((rev == 9) ? 0.2 : 0),
             d=floor_d + 2*bore_clr, center=true);
    // rev9: pockets for the steel well walls (flanges), Ø149->Ø165 x 7.25/side
    if (rev == 9) rev9_flange_pockets();
    // core: everything inside Ø129 removed (casing + fins pass through)
    cylinder(h=400, r=ring_in_r, center=true);
    // bolt holes, tangential through each boss pair
    if (with_bosses) for (a=joints) rotate([0,0,a])
      translate([(ring_in_r + ring_out_r)/2, 0, ring_z0 - boss_th/2])
        rotate([90,0,0]) cylinder(h=70, d=bolt_d, center=true);
  }
}
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

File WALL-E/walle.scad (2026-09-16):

// ============================================================================
//  WALL-E — THE GLOBAL FILE
// ============================================================================
//
//  One entry point for the whole robot. Everything downstream of here is
//  derived; there are no numbers in this file that are not about drawing.
//
//  WHAT THIS FILE IS FOR
//
//    1. A single command that renders any view of the robot, so you never
//       have to remember which sub-file holds what.
//    2. DIMENSIONED BLUEPRINT SHEETS. Not pretty pictures — drawings with
//       witness lines, arrows and numbers on them, which is what you actually
//       take to a workshop. OpenSCAD has no dimensioning, so section 2 below
//       builds one.
//
//  WHERE THE NUMBERS COME FROM
//
//    pod_interface.scad     the 23 facts about the BUILT pods. Verified
//                           against the pod model; run check_pod_interface.scad
//    cad/walle_frame.scad   everything WALL-E actually decides, plus 46 guards
//
//  HOW TO USE IT
//
//    ./render_all.sh                      every sheet and every view, in one go
//    openscad walle.scad                  open it and pick a mode in the GUI
//    openscad -o out.png -D 'view="s1"' walle.scad
//
//  THE MODES
//
//    Blueprint sheets, 2D, dimensioned — these are the drawings:
//      s1   General arrangement: front and side, overall sizes
//      s2   Frame weldment: what the welder needs. Steel only, with holes
//      s3   Battery box: all six plywood panels flat, with hole positions
//      s4   Chest panel and speakers: cutout positions
//      s5   Electronics shelf: what sits where
//
//    Solid views, 3D — these are for looking at and for STL export:
//      robot, frame, head, chest, shelf, section, assembly, plates
//
// ============================================================================

// The list in the comment below is what gives you a DROPDOWN in OpenSCAD's
// Customizer panel instead of a plain text box. It has to sit on the same line
// as the assignment, and the values have to match the dispatch at the bottom
// of this file by hand — OpenSCAD cannot read them out of the code.
view = "s1"; // [s1:Sheet 1 general arrangement, s2:Sheet 2 frame weldment, s3:Sheet 3 battery box, s4:Sheet 4 chest panel, s5:Sheet 5 electronics shelf, robot:Whole robot, frame:Steel frame only, section:Cut in half, head:Head only, chest:Chest and speakers, shelf:Electronics shelf]

// Pull in the whole model for its numbers and its modules, but stop it from
// drawing itself on top of our sheets.
no_render = true;
include <cad/walle_frame.scad>

// ============================================================================
//  2. A DIMENSIONING LIBRARY
// ============================================================================
//  OpenSCAD cannot dimension a drawing, so this is the minimum that makes a
//  sheet readable: an extension line off the feature, an arrow at each end,
//  and the number sitting on the line.
//
//  Everything takes a scale `s`. A sheet 3 metres across and a sheet 300 mm
//  across need very different arrow and text sizes, and hard-coding them is
//  what makes drawings unreadable when you change the zoom.
// ============================================================================

lw      = 2.5;    // line weight, in model units, scaled by s
arrow_l = 9;      // arrow length
arrow_w = 3.5;    // arrow half width
txt     = 15;     // text height
gap     = 6;      // witness line does not touch the feature

module bp_line(p0, p1, s = 1){
  d = [p1[0] - p0[0], p1[1] - p0[1]];
  l = sqrt(d[0]*d[0] + d[1]*d[1]);
  if (l > 0.001)
    translate(p0) rotate([0, 0, atan2(d[1], d[0])])
      translate([0, -lw*s/2]) square([l, lw*s]);
}

module bp_arrow(tip, ang, s = 1){
  translate(tip) rotate([0, 0, ang])
    polygon([[0,0], [arrow_l*s, arrow_w*s], [arrow_l*s, -arrow_w*s]]);
}

// horizontal dimension: from x0 to x1, drawn at height y
module dim_h(x0, x1, y, label, s = 1, flip = false){
  bp_line([x0, y], [x1, y], s);
  bp_arrow([x0, y], 0, s);
  bp_arrow([x1, y], 180, s);
  translate([(x0 + x1)/2, y + (flip ? -txt*s*1.6 : txt*s*0.5)])
    text(label, size = txt*s, halign = "center", valign = "baseline");
}

// vertical dimension: from y0 to y1, drawn at x
module dim_v(y0, y1, x, label, s = 1, left = false){
  bp_line([x, y0], [x, y1], s);
  bp_arrow([x, y0], 90, s);
  bp_arrow([x, y1], -90, s);
  translate([x + (left ? -txt*s*0.6 : txt*s*0.6), (y0 + y1)/2])
    rotate([0, 0, 90])
      text(label, size = txt*s, halign = "center",
           valign = left ? "top" : "baseline");
}

// Hollow out an already-2D shape. Note this is ONE module level with two
// children() calls, which works; the three-level version further down does
// not, and the comment there explains why.
module o2(t = 3){
  difference(){ children(); offset(delta = -t) children(); }
}

// a witness line, to carry a dimension away from the part
module wit(p0, p1, s = 1){ bp_line(p0, p1, s); }

// a leader with a note on the end
module note(from, to, label, s = 1, halign = "left"){
  bp_line(from, to, s);
  bp_arrow(from, atan2(from[1] - to[1], from[0] - to[0]), s);
  translate([to[0] + (halign == "left" ? txt*s*0.4 : -txt*s*0.4), to[1]])
    text(label, size = txt*s, halign = halign, valign = "center");
}

// ring a feature that needs pointing out
module ring(c, d, s = 1){
  translate(c) difference(){
    circle(d = d + 4*lw*s, $fn = 48);
    circle(d = d, $fn = 48);
  }
}

// A drawing border. It is not decoration: --viewall frames whatever the
// widest geometry is, so without a border every sheet gets framed to its own
// stray dimension text and ends up a different size with random margins. With
// one, the border IS the widest thing and the drawing fills the page.
module sheet_frame(x0, y0, x1, y1, s = 1){
  b = lw*s*1.6;
  difference(){
    translate([x0, y0]) square([x1 - x0, y1 - y0]);
    translate([x0 + b, y0 + b]) square([x1 - x0 - 2*b, y1 - y0 - 2*b]);
  }
}

// a title block, bottom left of every sheet
module title_block(x, y, sheet, name, s = 1){
  t = txt*s;
  translate([x, y]){
    difference(){
      square([t*34, t*6.4]);
      translate([lw*s, lw*s]) square([t*34 - lw*s*2, t*6.4 - lw*s*2]);
    }
    translate([t*0.9, t*4.4]) text(str("WALL-E  ", sheet), size = t*1.2);
    translate([t*0.9, t*2.7]) text(name, size = t*0.85);
    translate([t*0.9, t*1.1])
      text("all dimensions mm · generated by walle.scad · do not hand-edit",
           size = t*0.55);
  }
}

// ============================================================================
//  3. OUTLINES
// ============================================================================
//  A blueprint wants line work, not a filled silhouette. These project the
//  REAL 3D model and then hollow the result, so the outline can never drift
//  away from what the model says.
//
//  The model is Y-up and its front is +x, so:
//    front view   rotate([0,90,0])   -> sheet x = model z, sheet y = model y
//    side  view   no rotation        -> sheet x = model x, sheet y = model y
//    top   view   rotate([90,0,0])   -> sheet x = model x, sheet y = -model z
// ============================================================================

//  Each view does its own hollowing. It would read better as
//  `outline(t) projection() ... children()`, and that is how it was written
//  first, but it silently produced SOLID SILHOUETTES: chaining children()
//  through two module levels leaves the second instantiation empty, so the
//  subtraction removed nothing. Two direct children() calls inside one module
//  are fine, so each view repeats the projection instead.
module view_front(t = 4){
  difference(){
    projection() rotate([0, 90, 0]) children();
    offset(delta = -t) projection() rotate([0, 90, 0]) children();
  }
}
module view_side(t = 4){
  difference(){
    projection() children();
    offset(delta = -t) projection() children();
  }
}
module view_top(t = 4){
  difference(){
    projection() rotate([90, 0, 0]) children();
    offset(delta = -t) projection() rotate([90, 0, 0]) children();
  }
}

// the robot without the ground plane, which would swamp every projection
module robot_nog(){
  if (show_pods) for (s = [1,-1]) translate([0, 0, s*pod_z]) pod();
  frame_steel(); pod_bolts(); battery_box();
  if (show_batteries) batteries();
  anti_tip(); risers(); body_shell(); shelf_layout();
  if (show_speakers) { speaker_boxes(); speakers(); }
  head();
}
module steel_only(){ frame_steel(); anti_tip(); risers(); }
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

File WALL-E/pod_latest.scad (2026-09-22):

// GENERATED by pod_latest.sh — do not hand-edit.
// WALL-E always reads the NEWEST pod revision on disk. Today that is rev013-double-shear.
pod_latest_rev  = "rev013-double-shear";
pod_latest_file = "../archive/rev013-double-shear/apollo_track_pod_rev013.scad";
include <../archive/rev013-double-shear/apollo_track_pod_rev013.scad>

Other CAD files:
stl/rev010_half_B.stl
archive/rev009-uncut-11T/plates_rev009.dxf
archive/rev010-cut-rim-10T-final/plates_rev010.dxf
archive/rev013-double-shear/rev012_plates.dxf
archive/rev013-double-shear/plates_rev011.dxf
archive/rev010-cut-rim-10T-final/stl/rev010_half_B.stl
WALL-E/cad/check_pod_interface.scad
WALL-E/cad/eye/eye_cartridge.scad
WALL-E/cad/pod_interface.scad
WALL-E/cad/pod_latest.scad
WALL-E/cad/walle.scad
WALL-E/cad/walle_frame.scad
archive/rev003a/apollo_track_pod.scad
archive/rev005c/apollo_track_pod.scad
archive/rev007-cut-rim-10T/apollo_track_pod.scad
archive/rev008-cut-rim-9T/apollo_track_pod.scad
archive/rev009-uncut-11T/apollo_track_pod_rev009_uncut.scad
archive/rev010-cut-rim-10T-final/apollo_track_pod.scad
archive/rev011-uncut-11T-lowB/apollo_track_pod_rev011.scad
archive/rev012-inline-batteries/apollo_track_pod_rev012.scad
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

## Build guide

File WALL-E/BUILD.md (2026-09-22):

# Building WALL-E

This is the order to build the robot in, with the check to do at the end of each
step. Every number here comes out of `walle.scad`. None of it is typed in by
hand, so if you change the model, run `./render_all.sh` and this file's drawings
change with it.

Front of the robot is **+x**. When a drawing says "front to the right", that is
what it means.

## The files

| File | What it is |
|---|---|
| `walle.scad` | The global file. One entry point, every view and every sheet. |
| `pod_interface.scad` | The 23 facts about the **built** pods. The only place they live. |
| `check_pod_interface.scad` | Proves that file still matches the real pod model. |
| `cad/walle_frame.scad` | Everything WALL-E decides, plus 46 guards. |
| `render_all.sh` | Regenerates every sheet and every view. |
| `blueprint/s1..s5.png` | The dimensioned drawings. |

To redraw everything:

```sh
cd WALL-E
./render_all.sh
```

It checks the pod numbers and the 46 guards first, and stops if the pod numbers
do not match. That is on purpose: if the pod interface is wrong, every dimension
on every sheet below it is wrong too.

## The sheets

| Sheet | Title | Use it for |
|---|---|---|
| `blueprint/s1.png` | General arrangement | Overall sizes, and every important height |
| `blueprint/s2.png` | Frame weldment | **Give this to the welder** |
| `blueprint/s3.png` | Battery box, 6 panels | **Give this to whoever cuts the plywood** |
| `blueprint/s4.png` | Chest panel / speaker baffle | Cutting the two speaker holes |
| `blueprint/s5.png` | Electronics shelf | Placing the boxes and running the cable |

## The headline numbers

| | |
|---|---|
| Overall | 910 mm tall, 677 mm wide, 430 mm body length |
| Weight | about 100 kg, and **that is a guess** — see step 0 |
| Lowest point | the plywood box floor, 150 mm above the ground |
| Tips forward at | 17.7°, and the castor catches it at 12.3° |
| Speakers | two 6.5 inch, 10.1 litres of sealed air behind each |

---

# Step 0. Before you cut anything

The part weights are still assumptions, and the pod joint is worth a tape
measure. Both are cheap to check now and expensive to discover later.

### 0a. Which face does the rail bolt to? (answered — but look anyway)

This used to be an open question. Rev 013 measured the built pods on
2026-09-18 and closed it:

- The green plates **are** fitted, but they sit **inboard** of the carriers, at
  76.5 to 82.5 mm from the pod centre.
- The carrier is next, 82.5 to 88.5, so it stands **6 mm proud** of the plate.
- The rail therefore **lands on the carrier**, at 88.5. The robot is 677 mm
  wide overall.
- The two M12 holes are in the **green plate**, 6 mm behind that face. Each
  side gets a **6 mm packer** (a 60×6 offcut, 2 holes Ø13) filling the gap.

Without the packer the bolts pull the rail wall into the air gap and the joint
has no clamp at all. Do not skip it.

Go and look at the physical pods anyway, and check the table in step 0a2. The
scooter's fork legs, if they are still bolted on at 88.5 to 92.5, come **off**
for WALL-E — they belong to the scooter.

Full stack, part by part: [FRAME_AND_PODS.md](FRAME_AND_PODS.md).

### 0a2. Measure the gap between the fork legs before you cut anything

**Do this one with a tape measure, not by trusting this document.**

On 2026-09-17 the checker found that the WALL-E frame had been built on
`fork_gap = 168` when the real Rev 012 value is **140**. The 168 came from a
proposal to widen the carrier spacing that was then reverted, so it had never
been true. The frame was **14 mm per side too wide**, and the drawings said
700 mm overall when the answer is 672.

It is fixed now. But it is exactly the kind of error that survives right up to
the moment the steel is already cut, so verify it yourself:

| Measure | Should be |
|---|---|
| Clear gap between the two carrier plates | 165 mm |
| Over the carriers, outer face to outer face | 177 mm |
| Over the two green plates | 165 mm |
| Carrier plate thickness | 6 mm |
| Green plate thickness | 6 mm |
| Green plate band, bottom and top above ground | 197 and 257 mm |
| M12 hole centres, forward of the hub axle | 108 and 168 mm |

If any of these differ, change them in `pod_interface.scad`, then run:

```
cd WALL-E
./pod_latest.sh
openscad -o chk.echo --export-format echo check_pod_interface.scad
./render_all.sh
```

The checker tells you whether the numbers still match the pod model, and the
render script re-cuts every drawing. Never edit a dimension in `walle_frame.scad`
to work around a pod measurement.

### 0b. Weigh things

The tipping angles are the only thing keeping the robot off its face, and they
are computed from these guesses:

```
pod 15 kg each · battery 8 kg each · electronics 6 kg · body 25 kg · head 5 kg
```

Put a pod on a bathroom scale. Weigh a battery pack. Then open
`cad/walle_frame.scad`, find the block marked `STILL GUESSES`, replace the
numbers, and re-run. If the forward tipping angle drops below about 15°, stop
and move weight backwards before you build the body.

**Check:** `./render_all.sh` prints `all 46 guards pass` and
`ALL 23 NUMBERS AGREE`.

---

# Step 1. Cut the steel

From sheet 2. All of it is 60x30x3 box tube except the castor legs.

| Part | Count | Length |
|---|---|---|
| Rail | 2 | 550 mm |
| Cross member | 2 | 240 mm |
| Castor leg, 30x30 box | 2 | 87 mm |
| Castor fore/aft tie | 2 | — |

That is 1580 mm of 60x30 box in total.

**Check:** both rails are the same length to within 1 mm. If they are not, the
bay will not be square and the pods will toe in or out.

---

# Step 2. Drill the rails

This is the step to get right, because the holes in the pods already exist and
cannot move.

Each rail gets **2 holes Ø25, straight through both walls**:

- at **107 mm and 167 mm from the rail's REAR end**
- **30 mm up from the rail's bottom edge**

Then **weld a Ø25 / Ø13 x 30 mm sleeve into each hole.** The sleeve is what
carries the load across both walls of the box section. Without it you are
crushing a 3 mm wall with an M12 bolt.

> The rear end is the **−x** end. This file used to say "front end" and the
> distances were being measured from the rear, which would have put both holes
> 336 mm out of place. Measure from the rear.

**Check:** hold a rail against a pod, flat on the **carrier** face, with the
6 mm packer between the rail and the green plate. The two sleeves should line up
with the two drilled holes in the plate with no forcing. Do this before you weld
anything else.

---

# Step 3. Weld the frame

From sheet 2, plan view. Distances are from the rail's rear end.

- Rail outer faces **323 mm apart**, so **263 mm clear** between them.
- Rear cross member at **25 mm**.
- Front cross member at **525 mm**.
- Both cross members sit **between** the rails, so cut them to the bay: **263 mm**.

The rails end up sitting **197 to 257 mm above the ground**, which is flush with
the green plates.

Then the anti-tip legs: two 87 mm uprights with Ø75 castors, 280 mm out from the
centre, set so the castor wheel is **35 mm clear of the ground**.

**Check:** measure both diagonals across the bay. They must match. Then check
the clear bay is 268 mm at both ends, not just in the middle.

---

# Step 4. Bolt the frame to the pods

Four M12 10.9 bolts, two per side, through the rail into the nut on the green
plate.

Tighten to a normal M12 10.9 torque. Each bolt only sees about 1.2 kN of the
50 kN of preload available, so the joint is nowhere near its limit — the margin
is in the plates, not the bolts.

**Check:** stand back and look at it from the front. Both pods should be
vertical and the frame level. Then push the robot. **The whole pod comes off
with two bolts per side** — that is the point of this joint, so make sure you
can still reach all four heads.

---

# Step 5. The battery box

From sheet 3. Six panels of 12 mm plywood, cut from one sheet.

| Panel | Count | Size |
|---|---|---|
| Floor | 1 | 444 x 240 |
| Side wall | 2 | 444 x 142 |
| End wall | 2 | 240 x 142 |
| Lid | 1 | 444 x 240 |

The side walls are **handed**. Each one gets two **Ø30 holes at 54 mm and
114 mm from the rear edge, 77 mm up**. Those are spanner access for the M12 pod
bolts, not ventilation.

The lid gets **12 x M5 round the edge at 110 mm pitch**, and **one Ø12 screw-in
membrane vent in the centre**, sitting over the gap between the two packs.

Assembly order:

1. Floor and four walls. The end walls are what actually close the box.
2. **3 mm closed-cell foam tape on every face the lid touches.**
3. Batteries in, standing upright: 80 mm wide, 110 mm tall.
4. **8 mm foam pad on top of the packs**, so the lid holds them down.
5. Lid on, 12 x M5.
6. **4 x Ø30 silicone blanking plugs** into the spanner holes.

The plugs go in **after** the pod bolts are torqued. If you seal them first you
will be cutting them out again.

### Charge the packs where they are

The box is sealed and there is no field-serviceable way into it. Run the charge
leads out through a gland and charge in place. Do not plan on lifting packs out
in sand.

**Check:** the box floor is **150 mm above the ground and is the lowest part of
the whole robot.** Everything you drive over has to clear that, not the tracks.

---

# Step 6. The body and the chest panel

The body floor sits at **335 mm**, which is 8 mm over the pod belt crown. The
crown is higher than anything at frame level, so it is the crown that sets this
height, not the frame.

Body is **430 long x 620 wide x 400 tall**, on 78 mm risers off the rail tops.

The chest panel, from sheet 4:

- 12 mm plywood, **510 x 290**
- **set back 20 mm** from the body's front face
- **two Ø165 holes**, centres **280 mm apart**, **194 mm up from the panel's
  bottom edge**

The Ø190 driver rim lands on the panel face around each hole, with 20 mm of
margin left and right and 50 mm top and bottom.

**Check:** dry-fit a driver in each hole before you glue the panel in. The rims
must not touch each other — there should be 90 mm between them.

---

# Step 7. The speaker enclosures

One sealed box per driver, **260 deep x 258 tall x 205 wide** in 12 mm ply. That
gives **10.1 litres of air** behind each driver, which is in the middle of the
7 to 14 litre range a 6.5 inch driver wants.

**Bolt them to the chest panel. Do not glue them in.** Each one sits over the
electronics shelf with 20 mm of headroom and covers 54% of it. With both boxes
in place only **46% of the shelf is reachable**, so if they are glued you cannot
service the electronics without destroying something.

Seal every joint. A sealed box that leaks is an unsealed box, and it will chuff
and rattle at volume.

Fit the metal grilles.

**Check:** press a cone in gently with your palm. It should feel springy and
push back. If it moves freely, the box is leaking.

---

# Step 8. The electronics shelf

From sheet 5. The shelf is **356 x 546 at 347 mm**, four rows running fore and
aft. The parts use 32% of the area and the tallest box is 76 mm.

Mount everything **before** the speaker enclosures go in, and leave the cable
long enough that a box can be lifted out without unplugging the whole robot.

See `docs/04-power-and-wiring.md` for the wiring. The one thing worth repeating
here: the **amplifier gets its own 48 V to 32 V supply**, separate from the
logic supply. Sharing it puts motor noise straight into the speakers.

**Check:** with both enclosures bolted in, can you still reach every connector
you might need on a bad day at the festival? If not, move it now.

---

# Step 9. The head

**The neck is a rigid welded post. It is not a joint.** No bearing, no slip ring,
nothing to rotate and nothing to seal. The head does not pan, nod, or tilt.
To look left or right, the whole robot turns.

Neck 70 mm tall off the body top at 735 mm. Head centre at 858 mm, 233 mm wide,
two Ø105 barrels 128 mm apart. **Robot height 910 mm.**

Each eye is a 53 mm screen sunk **60 mm** into its barrel. That fills 50% of the
barrel and shades the screen from any sun above **49° elevation**. Negev midday
sun is 75 to 80°, so the screens are shaded when it matters.

**Check:** the barrels toe inwards. Check the two mouths clear each other —
there should be 7 mm between them. Rotate them through their full travel.

---

# Step 10. Before you drive it

1. Put it on level ground. Both castors should be **35 mm clear**.
2. Push down hard on the front. The castor must touch **before** the robot
   starts to go over. It catches at 12.3° and the robot goes over at 17.7°, so
   there is 5.4° in hand.
3. Drive it slowly on sand. Ground pressure is 0.184 kg/cm², about a third of
   what a walking person puts down, so it should float.
4. Watch the **box floor at 150 mm**, not the tracks. That is what grounds out.

---

# When you change something

```sh
cd WALL-E
./render_all.sh
```

Read the output. `all 46 guards pass` and `ALL 23 NUMBERS AGREE` means the
change is consistent. A `WARN` line names the clearance that has gone negative
and by how much. A `MISMATCH` means `pod_interface.scad` no longer agrees with
the pod model, and nothing below it can be trusted until that is fixed.

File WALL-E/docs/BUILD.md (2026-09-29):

# Building WALL-E

Order of work. Numbers from `cad/walle.scad`. Front = **+x**.

| File | |
|---|---|
| `cad/walle.scad` | Entry |
| `cad/pod_interface.scad` | 31 facts about the **built** pods |
| `cad/check_pod_interface.scad` | Must match the pod model |
| `cad/walle_frame.scad` | Everything else + guards |
| `cad/render_all.sh` | Check, redraw, rebuild guide |

```sh
cd WALL-E && cad/render_all.sh
```

Stops on pod mismatch. On purpose.

| Sheet | Use |
|---|---|
| 1 General | Heights |
| 2 Frame weldment | Give to the welder — step 3 |
| 3 Battery box | Plywood cut — step 5 |
| 4 Chest / speakers | Step 6 |
| 5 Shelf | Step 8 |

Sheet 1 — general arrangement. Overall sizes and every important height.

| | |
|---|---|
| Overall | 1003 H, 677 W, 430 body L |
| Mass | ~95 kg, **guess** — step 0 |
| Lowest | box floor 150 mm |
| Tips | 17.4°. Castor 12.3°. **5.1°** in hand |
| Speakers | 2 × 6.5 inch, 7.5 L each |

---

# Step 0. Before cutting

### 0a. Joint (rev013, measured)

- The frame **hangs from the pods' U braces**. Only the rear pod has green plates, so they are not used.
- Per pod: a hanger on the inboard carrier face, on the U brace's own inboard M12 (made M12×40). A tab on top, clamped to the U bridge with 4 × M10 beside the bridge.
- Both U bridges are the same height on the built pods (owner, 2026-09-29). The model uses 407 mm, **not measured yet**. Both hangers are 215 mm.
- Scooter fork legs come **off**.
- Full stack: [FRAME_AND_PODS.md](FRAME_AND_PODS.md).

### 0a2. Tape measure (do not trust this file)

| Measure | Should be |
|---|---|
| Clear between carriers | 165 mm |
| Over carriers | **177 mm** |
| U bridge top, front pod | 407 mm (rev013 draws 387) |
| U bridge top, rear pod | 407 mm |
| U brace M12 above ground | 268 mm |
| U bar | 40 × 6 mm |

If any differ: edit `cad/pod_interface.scad`, then `cad/pod_latest.sh`, checker, `cad/render_all.sh`. Never patch `walle_frame.scad` around a pod number.

### 0b. Weigh

Guesses in `cad/walle_frame.scad` (`STILL GUESSES`). Weigh a pod and a pack. If forward tip < ~15°, move mass back before the body.

**Check:** `every guard passes` and `ALL 31 NUMBERS AGREE`.

---

# Step 1. Cut steel

Sheet 2. 60×30×3 except castor legs.

| Part | Count | Length |
|---|---|---|
| Rail | 2 | 550 mm |
| Cross member | 2 | 251 mm |
| Castor leg, 30×30 | 2 | 82 mm |
| Castor tie | 2 | — |
| Hanger, 60×6 flat | 2 | 215 mm. Cut 10 mm long, trim to the measured bridge |
| Tab, 6 mm plate | 2 | 80 × 177 mm |
| Clamp plate, 6 mm plate | 4 | 80 × 30 mm |

1602 mm of 60×30. Rails same length ±1 mm.

---

# Step 2. Drill the hanger parts

The rails get **no holes**.

- Each hanger: **1 × Ø13**, centred, **76 mm up from the bottom end**. This is the U brace M12.
- Each tab: **4 × Ø11** at x ±27 mm, 39.5 and 149.5 mm from the inboard end.
- Each clamp plate: **2 × Ø11** at ±27 mm.
- Drill tab and clamps together, clamped as a stack, so the holes line up.

---

# Step 3. Weld

Sheet 2 — frame weldment. This is the drawing the welder works from.

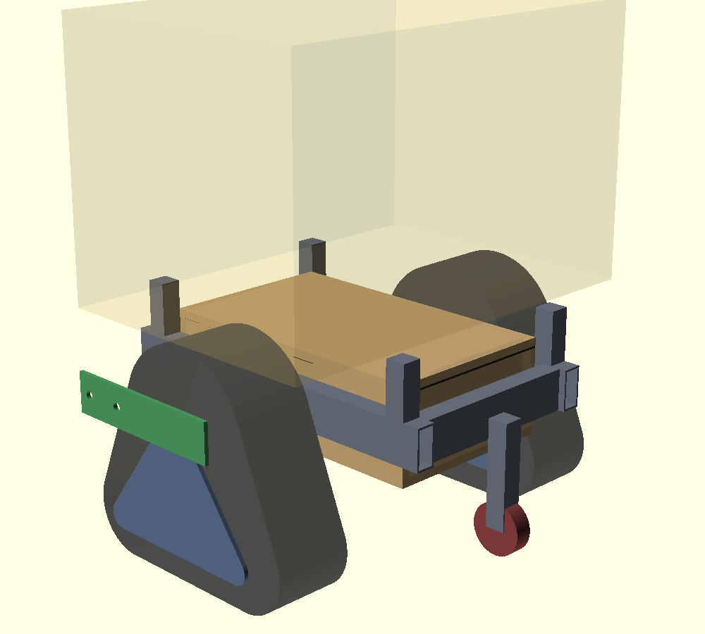
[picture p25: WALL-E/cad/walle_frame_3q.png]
The bare frame, three quarter view.


- Rail outer faces 311 mm apart. **251 mm clear.**
- Rear cross 25 mm. Front 525 mm. From rail rear. Crosses between the rails: 251 mm.
- Rails 192–252 mm above ground.
- Hanger centred 275 mm from each rail's rear end, bottom flush with the rail bottom. Rail outer face welded to the hanger.
- Tab: tack it on top of the hanger **with the frame sitting on the pods**, M12s and M10s in. The bridge heights are not measured yet, so do not trust a drawing here. Take it off, finish the welds.
- Anti-tip: 82 mm uprights, Ø75, 280 mm out, **35 mm** off the ground.

**Check:** diagonals match. Clear 251 mm at both ends.

---

# Step 4. Bolt to pods

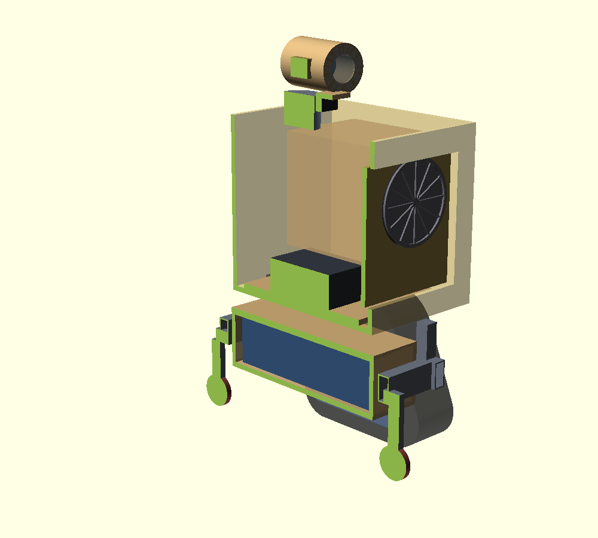
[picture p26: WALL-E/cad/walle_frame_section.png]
The robot cut in half, so you can see how the rail meets the pod and where the battery box hangs.


Per pod: take out the U brace's **inboard** M12×35. Put in an M12×40 through the U leg, carrier and hanger, nut on the hanger. Then 4 × M10×35 down through the tab, beside the bridge, into the clamp plates under it.

Pods vertical, frame level. Use a ring spanner on the M12 nut from above, with the body off.

---

# Step 5. Battery box

Sheet 3 — the battery box: six plywood panels, drawn flat for cutting.

| Panel | Count | Size |
|---|---|---|
| Floor, lid | 1 each | 444 × 251 |
| Side | 2 | 444 × 142 |
| End | 2 | 251 × 142 |

Sides have **no holes** now. Lid: 12 × M5 at 110 mm, Ø12 vent centre.

1. Floor + walls. 2. 3 mm gasket. 3. Packs in. 4. 8 mm pad. 5. Lid.

Daily charge: XT60 on the body. Lift-out: L17. Floor is **150 mm** and the lowest point.

---

# Step 6. Body and chest

Sheet 4 — chest panel and speaker baffle, with the two holes.

Floor 428 mm (8 mm over the M10 heads on the U tabs). Body 430 × 640 × 400 on 176 mm risers.

Chest: 530 × 290, set back 20 mm. Two Ø165, 330 mm apart, 194 mm up from panel bottom. Dry-fit drivers. 140 mm between rims. Each rim has 5 mm of plywood outboard. 7 inch LCD portrait 107 × 183 between them. Window 90 × 160. Bezel on the face.

---

# Step 7. Speaker boxes

260 × 200 × 205, 12 mm ply. **7.5 L.** Bolt on. Do not glue. Seal joints. Metal grilles. Cone should feel springy.

---

# Step 8. Shelf

Sheet 5 — the electronics shelf: what goes where, and where the cable runs.

Two floors. Lower 356 × 546 at 440 mm: controllers, contactor, fuses, Teensy, 12 V pack **flat**, PD 65 W+, amp. Upper 315 × 360 tray at 544 mm: XPS + USB hub. Hub from 12 V rail. Amp has its own 48→24 V.

Straps, not glue. Cables long enough for the tray. After boxes on: can you still reach connectors? Can 12 V and PD come out?

Wiring: `04-power-and-wiring.md`.

---

# Step 9. Head

Rigid post. No pan/nod/tilt. Look = body turn.

Neck 70 mm off body top at 828 mm. Head centre 951 mm, 233 mm wide. Barrels Ø105, 128 mm apart. Height **1003 mm**. Screen 53 mm, recess 60 mm. Shade above 49°. Mouths: 7 mm clear. Toe in.

Camera under the brow: ELP 42 × 42 × 36 mm.

---

# Step 10. Before driving

1. Level ground. Castors **35 mm** clear.
2. Push the front. Castor touches **before** it goes over (12.3° vs 17.4°).
3. Slow on sand. Watch the **150 mm** box floor, not the tracks.

---

# After a change

```sh
cd WALL-E && cad/render_all.sh
```

Need `every guard passes` and `ALL 31 NUMBERS AGREE`.

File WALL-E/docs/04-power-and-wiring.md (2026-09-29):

# 04 — Power and wiring

Physical version of `01-architecture.md`.

- One 48 V pack per pod. Positives never meet. Negatives + 12 V negative bonded at **one** point. Bond not fused.
- Electronics on their own 12 V pack (D8). **Contactor coils stay on pack A.**

## 1. Tree

```
PACK A 48 V ── XT60 ───┬── 30 A ── CONTACTOR A ── controller L ── left hub
                        ├── 10 A ── 48→24 V ── amp
                        └──  5 A ── E-stop chain ── both contactor coils (48 V)

PACK B 48 V ── XT60 ────── 30 A ── CONTACTOR B ── controller R ── right hub

12 V 20 Ah ── 15 A ── 12 V rail ── 12→5 V ── Teensy, ESP32
              (USB hub, fans). XPS is NOT on this rail.

PACK A (−) ══ 12 AWG bond, not fused ══ PACK B (−) ══ 12 V (−)
```

- E-stop kills **motors only**. Electronics stay up. E-stop is not an isolator. Isolator = XT60 (section 5).
- Both coils on one chain. Cutting one track only is a spin command. Never do that.

## 2. Current (91.6 kg)

| Case | Per side | Use |
|---|---|---|
| Straight, walking | ~2 A | Normal |
| Pivot on sand | ~8 A | Budget here |
| Start / rut | ~25 A | Seconds |
| Absolute | **40 A** | Wire and fuse must survive |

40 A is **measured**, not chosen. Controllers cannot change their peak. Clamp-meter at stall on blocks. Main fuse is **30 A** (10×38 gPV, owner 2026-09-29): 40 A bursts of seconds pass, a minute of stall does not. If the real peak is well above 40 A, rethink wire and fuse together. Teensy current control = back off throttle from ACS758. Slow.

## 3. 12 V rail

| Load | Cont. | Peak |
|---|---|---|
| USB hub | 10 W | 15 W |
| Fans | 5 W | 5 W |
| 12→5 V (Teensy, ESP32) | 5 W | 8 W |
| Chest 7 inch LCD | 8 W | 10 W |
| **Total** | **28 W** | **38 W** |

- XPS: own cells + USB-C PD **65 W+**. No 48→12, no boost from this pack.
- Pack: 12 V 20 Ah LiFePO4, 181 × 167 × 77 mm, **on its side**. 240 Wh / 28 W ≈ 8.5 h.
- 15 A fuse **at the terminal**. BMS is not a fuse.
- Own 14.6 V LiFePO4 charger. Label the three XT60s (two 48 V, one 12 V).

**Coils are 48 V on pack A**, 5 A slow-blow. Measure inrush (one listing claimed 167 W). Holding ~0.3 A.

| What dies | Contactors |
|---|---|
| Pack A | Coils die. Both open |
| 12 V pack | Teensy dies. Arm MOSFET opens chain |
| Pack B | Rule 4 only |
| Teensy crash, pack A alive | Watchdog only |

4700 µF on 12 V for fan/LiDAR inrush.

## 4. Amp

TPA3116D2 (owner, 2026-09-29; was TPA3255). Max **26 V**. A “48 V” pack is **54.6 V** full (13S) or **58.4 V** (16S LiFePO4). Dedicated **48→24 V 5 A (120 W)**, input **30–75 V**, off pack A through the 10 A fuse. Not on 12 V: bass peaks on the 12 V rail can reset the Teensy.

Check every part against **full** pack voltage.

## 5. Switches

| # | What | When |
|---|---|---|
| 1 | XT60 per pack | Before wiring, transport, overnight. **Only with the contactors open** |
| 2 | Mushroom E-stop | Emergency. Motors dead, electronics alive |
| 3 | Wireless E-stop | Must **open on signal loss**, not only on a stop message |
| 4 | Arm switch on TX | Session start/stop. Software |

Every 48 V fuse is 10×38 mm gPV, 1000 V DC (30 / 10 / 5 A). Blade and J-case fuses are 32 V: 12 V side only.

XT60 for the disconnect (owner, 2026-09-29; was XT90-S). It has **no anti-spark resistor**, so **plug and unplug only disarmed, contactors open**: the controller capacitors then sit behind the open contactor and the contacts do not arc. Plugging in armed burns the pins a little every time. 30 A continuous is fine for ~8 A cruising and 40 A bursts.

**Socket half on the battery.** Live pins on the pack = unfused short. Cap both halves.

```
PACK A + ── 5 A slow-blow ── mushroom NC ── wireless NC ── Teensy arm MOSFET
                                                      ├── coil A
                                                      └── coil B ── PACK A −
```

Contactor must be **DC-rated** ≥ 48 V 80 A. AC-rated welds shut.

Non-emergency: Spine ramps to zero, then drops the contactor. Mushroom does not wait. TVS on each controller input.

## 6. Wire

| Run | Gauge |
|---|---|
Three sizes only (owner, 2026-09-29). All silicone.

| Run | Gauge |
|---|---|
| Pack → 30 A fuse → contactor → controller | 12 AWG |
| Phases | owned motor cable |
| Ground bond | 12 AWG, short, **not fused** |
| 12 V pack → rail | 12 AWG (15 A fuse) |
| Amp 48→24 and 24 V | 16 AWG |
| 12 V distribution | 16 AWG |
| Coils, E-stop chain | 16 AWG |
| Throttle, reverse, e-brake | 22 AWG **shielded** |
| Halls / thermistors | 22 AWG shielded, away from phases |

Ring terminals: 12 AWG → yellow RV5.5, 16 AWG → red RV1.25, one HS-30J crimper.

## 7. Throttle path

```
Teensy 3.3 V I2C → level shift 5 V → 2× MCP4725 → opto → controller throttle
                 → pin 5 kick → watchdog → NC relay shorts both throttles
```

1. Relay is not optional. DAC holds last voltage.
2. Failed DAC write → stop kicking. Test 16.
3. Shielded, away from phases. Noise is throttle.
4. Opto isolate. Controller throttle ground is that pack’s negative.

## 8. Survive Midburn

- Crimp moving wires. Do not solder.
- Strain-relieve every connector.
- Signal crosses phases at 90°.
- Fan **in**, filter on inlet. Positive pressure.
- Nothing important on the body floor.
- Label both ends of every wire.

## 9. Commissioning

Bench supply 48 V, **2 A limit**. Packs last.

1. Bond negatives only. One ground path.
2. Coil chain, no contactors. Each of four breaks opens it.
3. Contactors on the bench. Both click.
4. 12 V pack + 15 A. 12 V on the rail. One path 12 V− to pack−.
5. Spine on. Arm holds contactors.
6. Controllers, no motors. Throttle 0–3.3 V follows Teensy.
7. One motor on blocks. Stops on every §3 fault.
8. Second motor. Steers in the air.
9. Watchdog: kill Teensy power while a motor runs. Relay opens.
10. Real packs. Then `03-safety-log.md`.

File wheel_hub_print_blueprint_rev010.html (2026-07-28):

# Wheel-hub printed drive sprocket — Rev 010 — 10T on the CUT rim floor (design of record)

2026-07-28 · companion files: sprocket_print.scad (rev=10) · STLs: stl/rev010_half_A.stl, stl/rev010_half_B.stl, stl/rev010_test_arc.stl · geometry locked to archive/rev010-cut-rim-10T-final

What is new vs the assembly model: the .scad rev models draw the sprocket as rib + teeth only (visual). This blueprint adds the parts that make it a printable, installable component: the drum clamp shell, the two-half split, and an under-floor bolt ring on the non-fin side so the halves bolt to each other through the open space between the hub’s 5 fins. The bolt ring and bosses are a new design addition — verify fin clearance on the real wheel before printing (checklist below).

## 1 · Key dimensions

Teeth | 10 T-teeth @ 36° — tooth marks every 56.2 mm on the rib top
Belt face (rib top) | Ø179 · cord circle Ø191 (belt: 60 mm pitch, 18 links, T = 12)
Drum seat | bore Ø149.4 = Ø149 floor + 2 x 0.2 fit clearance (tune with test arc) x 20.5 wide
Centre rib | 18 wide x 14.99 tall — rides the 22 mm gap between the belt lug pairs
T-tooth | 51 across x 20 thick, +5 root widening over the rib zone; outboard blades drop to Ø149 beside the rim
Clamp shell | bore Ø149.4, OD Ø155 (3 mm skin, 2.8 effective after clearance) x 20.5 wide
Bolt ring (NEW) | under-floor ring on the non-fin side: Ø129..Ø144.8 x 8 thick, registers 0.2 off the rim face; tied into every tooth blade
Split | straight split: joint lines at 18° and 198° — both in tooth gaps (36° tooth grid) · 0.25° trimmed per face (~0.3 mm) so the clamp can close
Hardware | 2 x M4 x 30 cl.8.8 + nyloc + washers — one per joint line, tangential through the boss pairs (Ø4.4 holes)
Clearances (guarded) | ring OD to belt-lug tip sweep (Ø149): ≥2 mm · ring ID to motor casing (Ø123): 3 mm

## 2 · Section

## 3 · Face view, split & clocking

## 4 · Printing

- Material: ABS (or ASA). Orientation: axis vertical, bolt-ring face DOWN — teeth print as continuous layer planes (per the project README).
- Strength: ≥4 perimeters, ≥40% infill (gyroid/cubic), 0.2 layers; no cooling fan for layer adhesion (ABS).
- Supports: needed under the shell edge and rib overhangs between tooth stations (the connectors support the part at each tooth).
- Fit: bore_clr = 0.2 per side is the starting value — print the TEST ARC first and adjust for your printer’s ABS shrinkage before committing to the halves.

## 5 · Assembly

1. Degrease the drum seat (the bare ground floor).
2. Dry-fit both halves; the split faces should show a small even gap (~0.3 mm/side) — that gap is the clamp stroke.
3. Clock tooth #0 to your reference mark on the hub; confirm both bolt bosses sit between fins.
4. Bolts with washers both sides, nyloc nuts; tighten alternately until the gap closes evenly. Do not crush — snug + a quarter turn (ABS creeps; re-check after the first ride).
5. Spin check: rib runout ≤ 0.5 mm; tooth marks 56.2 mm apart on the rib top.

## 6 · Pre-print checklist (mandatory)

- Floor ≥ 20 wide and rim ring wall ≥ 3 BEFORE grinding — then grind the flange walls off
- Tape the bare floor: circumference must read 468 mm (= Ø149) — send the number before printing
- Print the TEST ARC first — clamp it on the floor; tune bore_clr until snug
- Verify the 5 fins sit at 72.0° nominal and the two bolt bosses (18° / 198° from tooth #0) land between them
- Tooth spacing check on the print: marks every 56.2 mm on the rib top (36°)

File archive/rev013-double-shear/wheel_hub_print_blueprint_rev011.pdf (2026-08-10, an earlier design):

## Wheel-hub printed drive sprocket — Rev 011 — 11T on the UNCUT factory rim (no-cut twin)

2026-07-28 · companion files: sprocket_print.scad (rev=9) · STLs: stl/rev011_half_A.stl, stl/rev011_half_B.stl, stl/rev011_test_arc.stl · geometry locked to archive/rev011-uncut-11T

What is new vs the assembly model: the .scad rev models draw the sprocket as rib + teeth only (visual). This blueprint adds the parts that make it a printable, installable component: the drum clamp well fill, the two-half split, and an under-floor bolt ring on the non-fin side so the halves bolt to each other through the open space between the hub’s 5 fins. The bolt ring and bosses are a new design addition — verify fin clearance on the real wheel before printing (checklist below).

### 1 · Key dimensions

Teeth | 11 T-teeth @ 32.73° — tooth marks every 56.6 mm on the rib top
Belt face (rib top) | Ø198.1 · cord circle Ø210.1 (belt: 60 mm pitch, 18 links, T = 12)
Drum seat | bore Ø149.4 = Ø149 floor + 2 x 0.2 fit clearance (tune with test arc) x 20.5 wide
Centre rib | 18 wide x 16.54 tall — rides the 22 mm gap between the belt lug pairs
T-tooth | 51 across x 20 thick, +5 root widening over the rib zone; outboard blades drop to Ø168.1 beside the rim
Well fill | bore Ø149.4 x 20.3 wide, OD Ø165 (flush with rim body)
Flange pockets | Ø165.8 x depth to |z| 17.75 — 0.4 radial / 0.1 axial clearance over the steel well walls (walls Ø149→Ø165, 7.25 wide each)
Bolt ring (NEW) | under-floor ring on the non-fin side: Ø129..Ø164 x 8 thick, registers 0.2 off the rim face; tied into every tooth blade
Split | bent split (11T is odd): joint lines at 16.4° and 180.0° — halves are 163.6° / 196.4° arcs, both joints still fall in tooth gaps · 0.25° trimmed per face (~0.3 mm) so the clamp can close
Hardware | 2 x M5 x 35 cl.8.8 + nyloc + washers — one per joint line, tangential through the boss pairs (Ø5.4 holes)
Clearances (guarded) | ring OD to belt-lug tip sweep (Ø168.1): ≥2 mm · ring ID to motor casing (Ø123): 3 mm

### 2 · Section

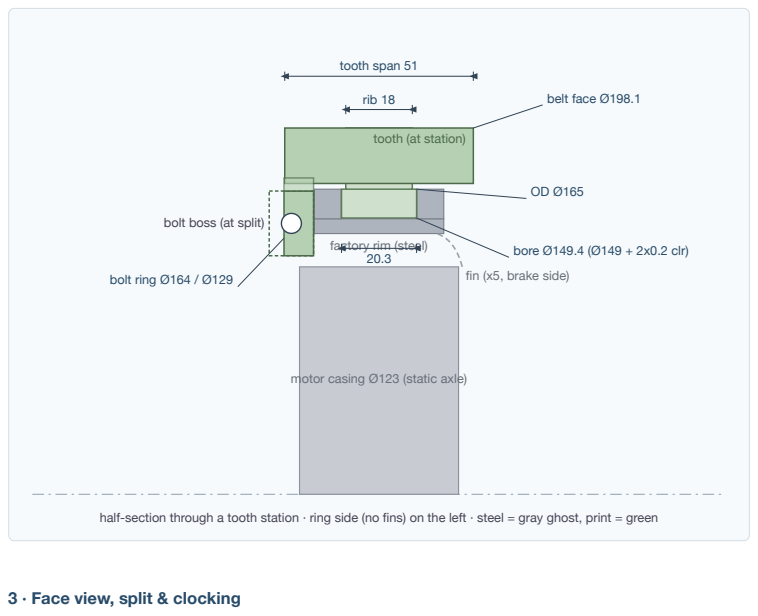
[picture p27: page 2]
tooth span 51; rib 18; belt face Ø198.1; bore Ø149.4 (Ø149 + 2x0.2 clr); bolt ring Ø164 / Ø129

tooth (at station)

bolt boss (at split)

factory rim (steel)

fin (x5, brake side)

motor casing Ø123 (static axle)

half-section through a tooth station · ring side (no fins) on the left · steel = gray ghost, print = green

3 · Face view, split & clocking

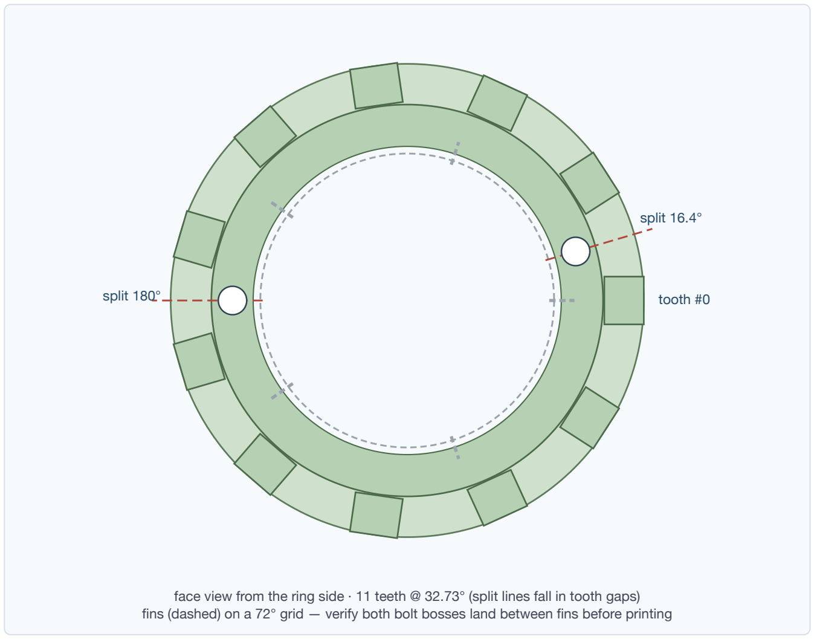
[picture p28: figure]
split 16.4°; split 180°; tooth #0

face view from the ring side · 11 teeth @ 32.73° (split lines fall in tooth gaps) fins (dashed) on a 72° grid — verify both bolt bosses land between fins before printing

### 4 · Printing

Material: ABS (or ASA). Orientation: axis vertical, bolt-ring face DOWN — teeth print as continuous layer planes (per the project README).
Strength: ≥4 perimeters, ≥40% infill (gyroid/cubic), 0.2 layers; no cooling fan for layer adhesion (ABS). Supports: needed under the fill edge and rib overhangs between tooth stations (the connectors support the part at each tooth).
Fit: bore_clr = 0.2 per side is the starting value — print the TEST ARC first and adjust for your printer’s ABS shrinkage before committing to the halves.

### 5 · Assembly

1. Degrease the drum seat (the tire well).
2. Dry-fit both halves; the split faces should show a small even gap (~0.3 mm/side) — that gap is the clamp stroke.
3. Clock tooth #0 to your reference mark on the hub; confirm both bolt bosses sit between fins.

4. Bolts with washers both sides, nyloc nuts; tighten alternately until the gap closes evenly. Do not crush — snug + a quarter turn (ABS creeps; re-check after the first ride).
5. Spin check: rib runout ≤ 0.5 mm; tooth marks 56.6 mm apart on the rib top.

### 6 · Pre-print checklist (mandatory)

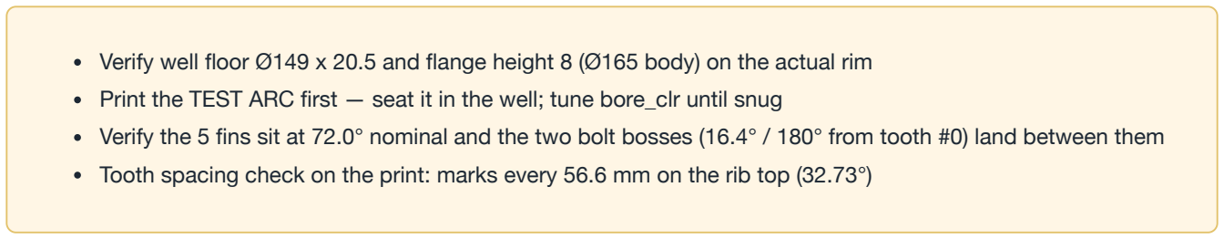
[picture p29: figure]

Verify well floor Ø149 x 20.5 and flange height 8 (Ø165 body) on the actual rim
Print the TEST ARC first — seat it in the well; tune bore_clr until snug
Verify the 5 fins sit at 72.0° nominal and the two bolt bosses (16.4° / 180° from tooth #0) land between them Tooth spacing check on the print: marks every 56.6 mm on the rib top (32.73°)

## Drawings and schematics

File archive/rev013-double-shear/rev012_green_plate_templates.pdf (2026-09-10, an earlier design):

60 | REV 012 · 1:1 TEMPLATE | 1/3

## GREEN PLATE RIGHT ×1

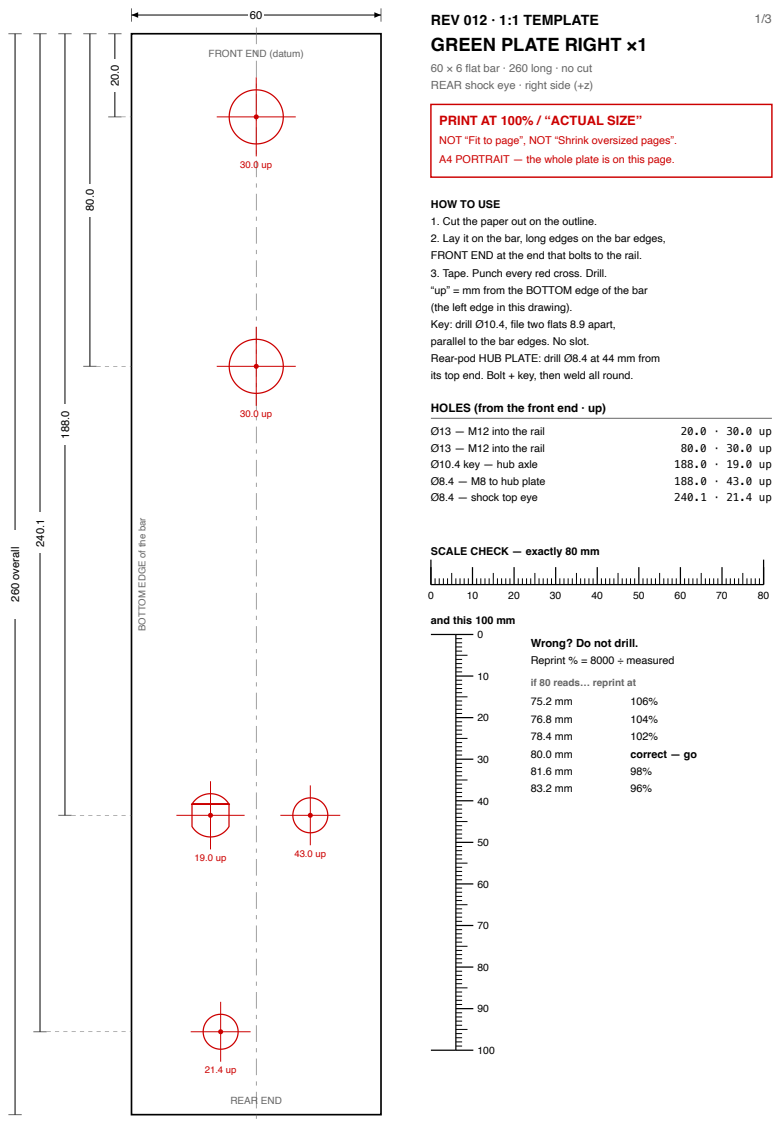
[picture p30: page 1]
REAR END; 260 overall; Ø13 — M12 into the rail; Ø10.4 key — hub axle; Ø8.4 — M8 to hub plate; Ø8.4 — shock top eye; correct — go

FRONT END (datum)

60 × 6 flat bar · 260 long · no cut
REAR shock eye · right side (+z)

PRINT AT 100% / “ACTUAL SIZE”
NOT “Fit to page”, NOT “Shrink oversized pages”.
A4 PORTRAIT — the whole plate is on this page.

HOW TO USE
1. Cut the paper out on the outline.
2. Lay it on the bar, long edges on the bar edges,
FRONT END at the end that bolts to the rail.
3. Tape. Punch every red cross. Drill.
“up” = mm from the BOTTOM edge of the bar
(the left edge in this drawing).
Key: drill Ø10.4, file two flats 8.9 apart,
parallel to the bar edges. No slot.
Rear-pod HUB PLATE: drill Ø8.4 at 44 mm from
its top end. Bolt + key, then weld all round.

HOLES (from the front end · up)

BOTTOM EDGE of the bar

SCALE CHECK — exactly 80 mm

and this 100 mm

Wrong? Do not drill.
Reprint % = 8000 ÷ measured

if 80 reads… reprint at

60 | REV 012 · 1:1 TEMPLATE | 2/3

## GREEN PLATE LEFT ×1

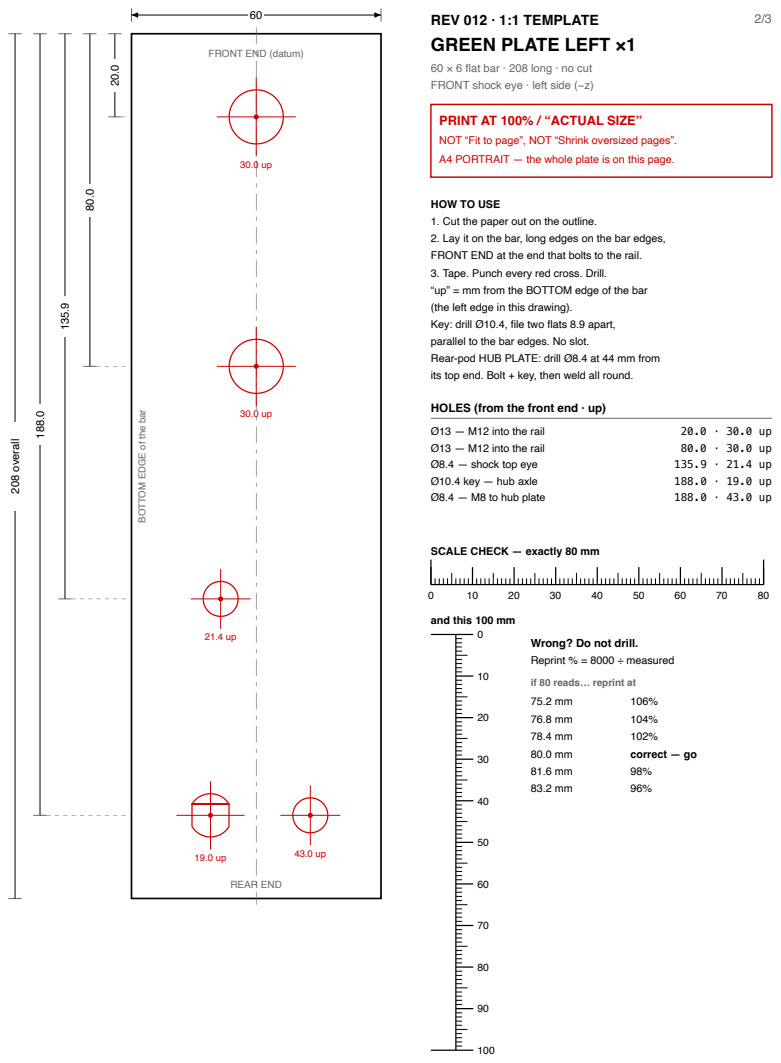
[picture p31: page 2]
REAR END; 208 overall; Ø13 — M12 into the rail; Ø8.4 — shock top eye; Ø10.4 key — hub axle; Ø8.4 — M8 to hub plate; correct — go

FRONT END (datum)

60 × 6 flat bar · 208 long · no cut
FRONT shock eye · left side (−z)

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

HOLES (from the front end · up)

BOTTOM EDGE of the bar

SCALE CHECK — exactly 80 mm

and this 100 mm

Wrong? Do not drill.
Reprint % = 8000 ÷ measured

if 80 reads… reprint at

REV 012 · 1:1 TEMPLATE — RAIL REAR END · 2 SLEEVE HOLES | 3/3

100 × 40 × 2 tube · use on BOTH walls of BOTH rails (4 times)

PRINT AT 100% / “ACTUAL SIZE” — NOT “Fit to page”, NOT “Shrink oversized pages”.
A4 PORTRAIT — the whole part is on this page. Check the ruler below BEFORE you drill.

REAR END of the rail (datum) — beside the rear pod

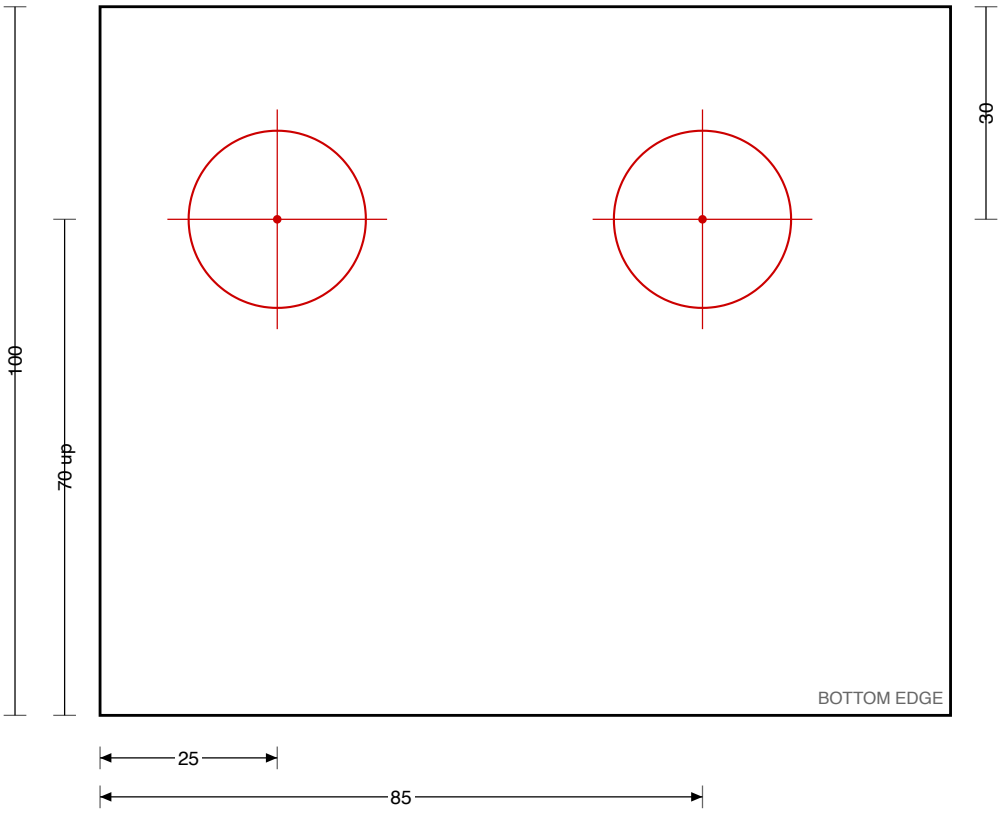
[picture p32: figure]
BOTTOM EDGE

Line up the REAR END and the BOTTOM EDGE every time — the holes are not in the middle. Best: drill a Ø6 pilot straight through both walls on a drill press, then open each side
to Ø25 with a hole saw. Weld a Ø25 × Ø13 × 40 steel sleeve into each pair of holes,
flush with both walls. The M12 goes in from OUTSIDE, through the sleeve and the green plate, into the M12 nut welded on the green plate.
0 | 10 | 20 | 30 | 40 | 50 | 60 | 70 | 80 | 90 | 100 | 110 | 120 | 130 | 140 | 150

SCALE CHECK — this scale must measure exactly 150 mm

0

10

20

30

40

and this one 50 mm
If it does not measure right, do not cut — reprint.
Reprint percentage = 15000 ÷ (the mm you actually measured).
Reads LONG = the dialog is enlarging; reads SHORT = shrinking. Either way: Actual size.
if the 150 mm scale reads… | reprint at
141 mm | 106%
144 mm | 104%
147 mm | 102%
150 mm | correct — go ahead
153 mm | 98%
156 mm | 96%

Paper also grows/shrinks with humidity — ±0.3 mm over 150 is normal.

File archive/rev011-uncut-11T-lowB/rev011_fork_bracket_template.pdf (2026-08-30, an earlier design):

## REV 011d BRACKET PLATES 1:1 - PORTRAIT - front (fork) end at TOP

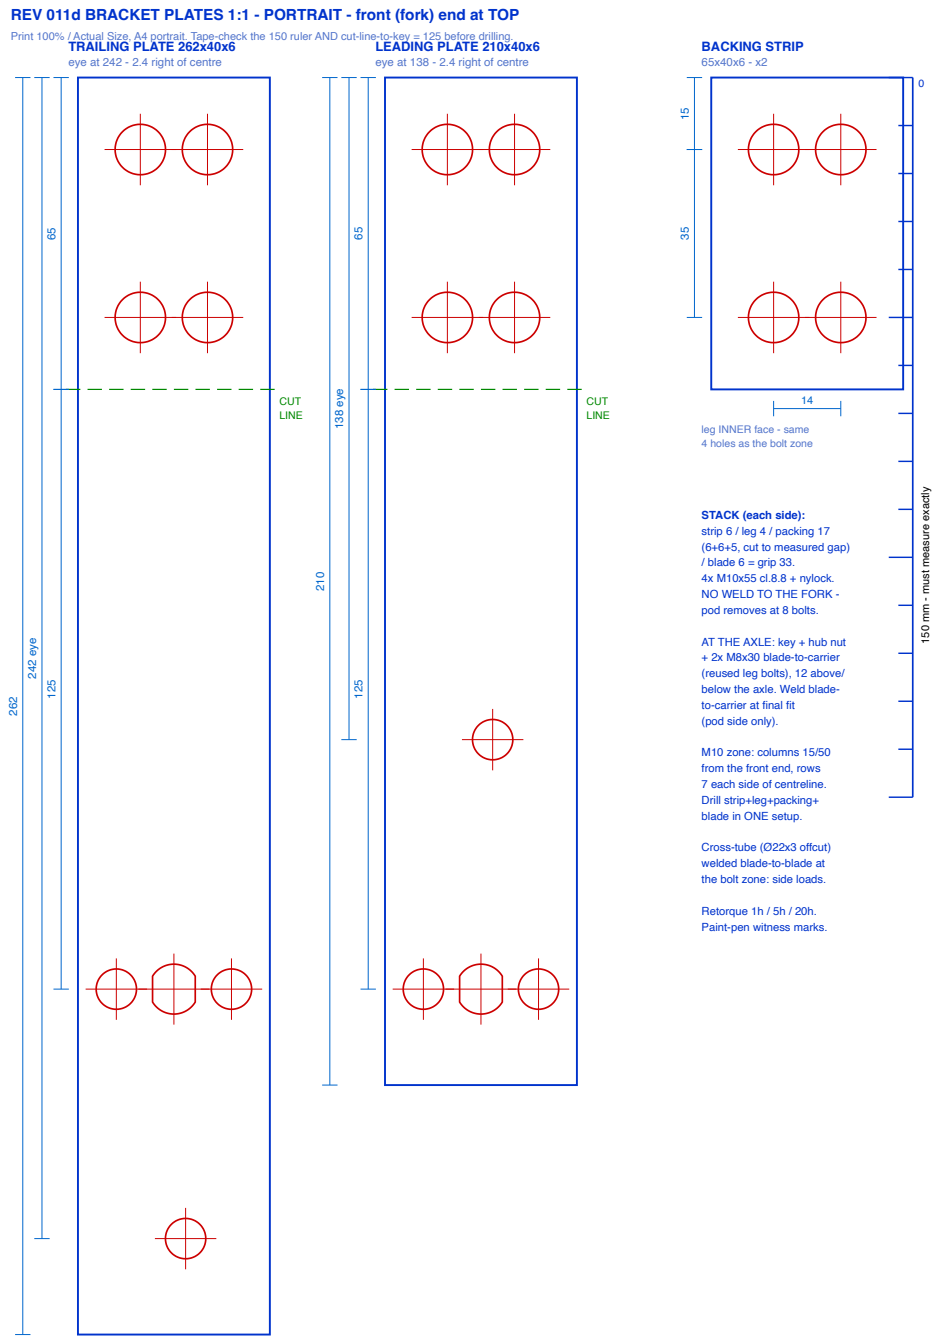
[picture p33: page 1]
CUT LINE; 242 eye; 138 eye; BACKING STRIP 65x40x6 - x2

Print 100% / Actual Size, A4 portrait. Tape-check the 150 ruler AND cut-line-to-key = 125 before drilling.

TRAILING PLATE 262x40x6
eye at 242 - 2.4 right of centre

LEADING PLATE 210x40x6
eye at 138 - 2.4 right of centre

leg INNER face - same
4 holes as the bolt zone

m - must measure exactly

STACK (each side):
strip 6 / leg 4 / packing 17
(6+6+5, cut to measured gap)
/ blade 6 = grip 33.
4x M10x55 cl.8.8 + nylock.
NO WELD TO THE FORK -
pod removes at 8 bolts.

AT THE AXLE: key + hub nut
+ 2x M8x30 blade-to-carrier
(reused leg bolts), 12 above/
below the axle. Weld blade-
to-carrier at final fit
(pod side only).

M10 zone: columns 15/50
from the front end, rows
7 each side of centreline.
Drill strip+leg+packing+
blade in ONE setup.

Cross-tube (Ø22x3 offcut)
welded blade-to-blade at
the bolt zone: side loads.

Retorque 1h / 5h / 20h.
Paint-pen witness marks.

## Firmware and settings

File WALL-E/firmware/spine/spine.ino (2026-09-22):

// spine.ino — the Spine. Teensy 4.0, no operating system.
//
// This board decides what the motors do. Nothing else on the robot is allowed
// to. It runs one loop at 1 kHz and rebuilds the motor commands from scratch
// every pass, in the fixed order described in docs/01-architecture.md section 3.
//
// ---------------------------------------------------------------------------
//  RULES FOR EDITING THIS FILE
// ---------------------------------------------------------------------------
//  1. No dynamic memory. No String. No malloc. Ever.
//  2. Nothing that can block. No delay(), no while-loop waiting on a device.
//  3. Nothing that takes unbounded time. No SD card, no display, no filesystem.
//  4. Every new failure case must ramp the motors to zero, not hold the last
//     value and not slam to zero.
//  5. If you are adding a feature rather than a safety check, it belongs on
//     the Brain, not here. Every line added here is a line that can stop the
//     robot from stopping.
//
// ---------------------------------------------------------------------------
//  REWRITTEN 2026-09-22 FOR DECISION D7 — scooter controllers, no data bus
// ---------------------------------------------------------------------------
//  The motors are driven by the two scooter controllers already owned. They
//  take a throttle VOLTAGE and tell you nothing back. So this file now:
//
//    * writes the throttle voltage with an MCP4725 DAC per side, and picks
//      direction with a separate opto-isolated reverse line;
//    * measures what the controllers do not report — pack volts, motor
//      temperature, pack current — with its own sensors;
//    * decides "is this track alive?" by counting the motor's hall edges;
//    * KICKS A HARDWARE WATCHDOG, and deliberately stops kicking it when it
//      can no longer trust its own outputs.
//
//  That last one is the important one. A scooter controller has no command
//  timeout and a DAC holds its last value forever, so if this board dies the
//  robot drives away. The only thing that stops it is the watchdog relay
//  shorting the throttle lines to ground. docs/01-architecture.md section 4.
//
// Build: Arduino IDE or PlatformIO with Teensyduino. Board = Teensy 4.0.
// Libraries: Wire only.

#include <Wire.h>
#include "config.h"

// ===========================================================================
//  STATE
// ===========================================================================
// Grouped by where it comes from, so it is obvious what is an input and what
// is a decision.

struct RcState {
  uint16_t ch[14]  = {0};
  uint32_t last_ms = 0;        // last frame that parsed
  uint32_t last_change_ms = 0; // last frame whose CONTENTS differed
  bool     valid   = false;    // a good frame arrived inside RC_TIMEOUT_MS
  bool     frozen  = false;    // frames arriving, contents not changing
} rc;

struct BrainState {
  float    speed   = 0.0f;    // -1 .. +1 requested
  float    turn    = 0.0f;
  uint32_t seq     = 0;
  uint32_t last_ms = 0;
  uint32_t ok_since_ms = 0;   // when it started being continuously alive
  bool     valid   = false;
} brain;

// One of these per side. This is what replaced VescState: nothing arrives on
// its own any more, every field is something this board measured.
struct SideState {
  float volts   = 0.0f;       // pack voltage, from the divider
  float temp_c  = 0.0f;       // hub motor thermistor
  float amps    = 0.0f;       // ACS758, telemetry only
  bool  sense_ok = false;     // the divider reading is plausible at all
  bool  alive   = true;       // rule 4: halls moving when commanded to
  int8_t dir    = 0;          // direction currently latched at the controller
  volatile uint32_t hall_edges   = 0;
  volatile uint32_t hall_last_ms = 0;
};
SideState side_l, side_r;

struct ToFState {
  uint16_t mm[TOF_COUNT] = {0};
  bool     valid[TOF_COUNT] = {false};
} tof;

// ---------------------------------------------------------------------------
//  Explicit prototypes. Do not delete them as "redundant".
//
//  The Arduino .ino preprocessor writes its own prototypes and inserts them
//  near the top of the file. That generation is unreliable for functions that
//  take a REFERENCE TO A USER-DEFINED TYPE: if a generated prototype lands
//  above `struct SideState`, the file stops compiling with an error that
//  points at a line nobody wrote. Declaring them here, after the struct, means
//  the compiler never needs the generated ones.
// ---------------------------------------------------------------------------
bool side_out(SideState &s, float duty, uint8_t rev_pin, uint8_t brake_pin,
              uint8_t dac_addr, uint32_t now);
void sense_side(SideState &s, uint8_t vpin, float vscale,
                uint8_t tpin, uint8_t cpin);
void side_alive(SideState &s, float duty, uint32_t now);
uint16_t throttle_counts(float mag);
bool dac_write(uint8_t addr, uint16_t value);
float therm_c(uint8_t pin);
float clampf(float v, float lo, float hi);
float slew1(float now, float want, float up, float down);

// What we last actually sent. The slew limiter works on these.
float duty_l = 0.0f, duty_r = 0.0f;

// Did the last throttle write actually reach both DACs? If not, this board is
// no longer in control of the motors, and it must stop kicking the watchdog.
bool output_ok = true;

// Why we are not moving, for telemetry. Index into STOP_REASON[].
enum StopReason : uint8_t {
  RUNNING = 0, R_ESTOP, R_UNARMED, R_NO_RC, R_RC_FROZEN, R_TRACK_DEAD,
  R_NO_SENSE, R_PACK_LOW, R_PACK_HIGH, R_NO_BRAIN, R_BUMPER, R_MOTOR_HOT,
  R_DAC_FAIL
};
const char* const STOP_REASON[] = {
  "running", "estop", "unarmed", "no_rc", "rc_frozen", "track_dead",
  "no_sense", "pack_low", "pack_high", "no_brain", "bumper", "motor_hot",
  "dac_fail"
};
StopReason stop_reason = R_UNARMED;

enum Mode : uint8_t { MANUAL = 0, ASSIST = 1 };
Mode mode = MANUAL;

// Stick activity overrides the Brain for a moment. docs/01-architecture.md s6.
uint32_t stick_override_until_ms = 0;

// ===========================================================================
//  HALL EDGES — arbitration rule 4's data source
// ===========================================================================
// One wire tapped from each motor's existing hall cable. We do not care about
// speed or direction here, only "is this thing turning at all". Counting one
// phase is enough for that and costs one interrupt.
void hall_l_isr() { side_l.hall_edges++; side_l.hall_last_ms = millis(); }
void hall_r_isr() { side_r.hall_edges++; side_r.hall_last_ms = millis(); }

// ===========================================================================
//  SETUP
// ===========================================================================
void setup() {
  // Arm output LOW first, before anything else, so a reset mid-drive drops
  // the contactors rather than leaving them held in.
  pinMode(PIN_ARM_OUT, OUTPUT);
  digitalWrite(PIN_ARM_OUT, LOW);

  // Then the throttle path, before anything can command movement: brakes on,
  // both directions forward, and (once I2C is up) the DACs at rest.
  pinMode(PIN_REV_L,   OUTPUT); digitalWrite(PIN_REV_L,   LOW);
  pinMode(PIN_REV_R,   OUTPUT); digitalWrite(PIN_REV_R,   LOW);
  pinMode(PIN_BRAKE_L, OUTPUT); digitalWrite(PIN_BRAKE_L, HIGH);
  pinMode(PIN_BRAKE_R, OUTPUT); digitalWrite(PIN_BRAKE_R, HIGH);

  // The watchdog line starts quiet. The relay is therefore CLOSED — throttle
  // shorted to ground — until this firmware has run a full pass and decided
  // it is healthy. Booting into "stopped" is the only safe way to boot.
  pinMode(PIN_WDT_KICK, OUTPUT);
  digitalWrite(PIN_WDT_KICK, LOW);

  pinMode(PIN_ESTOP_SNS, INPUT_PULLUP);
  pinMode(PIN_LED_OK, OUTPUT);
  pinMode(PIN_TOF_RESET, OUTPUT);
  digitalWrite(PIN_TOF_RESET, LOW);

  pinMode(PIN_HALL_L, INPUT_PULLUP);
  pinMode(PIN_HALL_R, INPUT_PULLUP);
  attachInterrupt(digitalPinToInterrupt(PIN_HALL_L), hall_l_isr, CHANGE);
  attachInterrupt(digitalPinToInterrupt(PIN_HALL_R), hall_r_isr, CHANGE);

  BRAIN_SERIAL.begin(115200);
  RC_SERIAL.begin(115200);          // iBus is 115200 8N1

  Wire.begin();
  Wire.setClock(I2C_HZ);
  dac_write(DAC_ADDR_L, throttle_counts(0.0f));
  dac_write(DAC_ADDR_R, throttle_counts(0.0f));

  tof_begin();
}

// ===========================================================================
//  MAIN LOOP — fixed rate, 1 kHz
// ===========================================================================
void loop() {
  static uint32_t next_us = 0;
  uint32_t now_us = micros();

  // Catch up rather than drift. If we ever fall behind, resync instead of
  // trying to run the missed iterations.
  if ((int32_t)(now_us - next_us) < 0) return;
  if ((int32_t)(now_us - next_us) > (int32_t)(LOOP_US * 5)) next_us = now_us;
  next_us += LOOP_US;

  uint32_t now = millis();

  // ---- inputs ----
  rc_poll();
  brain_poll();
  sense_poll();                     // volts, temperature, current
  tof_poll();                       // non-blocking, one sensor per pass
  freshness_check(now);

  // ---- decide ----
  arbitrate(now);

  // ---- outputs ----
  drive_out(now);                   // reverse lines, then the DACs
  wdt_kick(now);                    // ONLY if we still trust the outputs
  telemetry(now);
  digitalWrite(PIN_LED_OK, (now / 250) & 1);
}

// ===========================================================================
//  THE ARBITRATION — docs/01-architecture.md section 3
// ===========================================================================
// Read this top to bottom. The order IS the safety argument. A rule higher up
// always beats a rule lower down, and every exit path ramps to zero.
void arbitrate(uint32_t now) {
  float want_l = 0.0f, want_r = 0.0f;
  stop_reason = RUNNING;

  // --- Rule 1: the E-stop chain -------------------------------------------
  // Physical. If it is open the contactors are already out and the motors have
  // no power at all. We only sense it so we can say so, and so we refuse to
  // re-arm until the button is reset.
  bool estop_ok = (digitalRead(PIN_ESTOP_SNS) == LOW);
  if (!estop_ok) {
    stop_reason = R_ESTOP;
    hold_off();
    return;
  }

  // --- Rule 2: the arm switch ---------------------------------------------
  // The robot must never move the moment the battery is connected.
  bool armed = rc.valid && !rc.frozen && rc.ch[CH_ARM] > RC_SWITCH_ON;
  if (!armed) {
    stop_reason = R_UNARMED;
    hold_off();
    return;
  }

  // From here on the contactors may be held in.
  digitalWrite(PIN_ARM_OUT, HIGH);

  // --- Rule 3: is the radio alive? ----------------------------------------
  // Two ways for it to be dead. The second one still sends frames.
  if (!rc.valid) {
    stop_reason = R_NO_RC;
    ramp_to(0.0f, 0.0f);
    return;
  }
  if (rc.frozen) {
    stop_reason = R_RC_FROZEN;
    ramp_to(0.0f, 0.0f);
    return;
  }

  // --- Rule 3b: do we still control the throttle? -------------------------
  // New with D7. If a DAC write failed, the voltage on the controller is
  // whatever it was, and nothing this function decides can change it. Say so,
  // ramp down, and let wdt_kick() drop the relay.
  if (!output_ok) {
    stop_reason = R_DAC_FAIL;
    ramp_to(0.0f, 0.0f);
    return;
  }

  // --- Rule 4: is each track actually turning as commanded? ---------------
  // Both, not either. One dead track on a skid-steer robot does not stop it,
  // it makes it pivot. docs/01-architecture.md section 3b, trap 2.
  // The controllers report nothing, so this is the hall edges.
  if (!side_l.alive || !side_r.alive) {
    stop_reason = R_TRACK_DEAD;
    ramp_to(0.0f, 0.0f);
    return;
  }

  // --- Rule 5: are both pack voltages sane? -------------------------------
  // A missing or shorted divider reads as a plausible number near zero, which
  // would look like a flat pack. Separate it out so the telemetry tells the
  // truth: "no_sense" is a wiring fault, "pack_low" is a battery.
  if (!side_l.sense_ok || !side_r.sense_ok) {
    stop_reason = R_NO_SENSE;
    ramp_to(0.0f, 0.0f);
    return;
  }
  if (side_l.volts < PACK_FLOOR_V || side_r.volts < PACK_FLOOR_V) {
    stop_reason = R_PACK_LOW;
    ramp_to(0.0f, 0.0f);
    return;
  }
  if (side_l.volts > PACK_MAX_V || side_r.volts > PACK_MAX_V) {
    stop_reason = R_PACK_HIGH;
    ramp_to(0.0f, 0.0f);
    return;
  }

  // --- Rule 6: which mode? ------------------------------------------------
  mode = (rc.ch[CH_MODE] > RC_SWITCH_ON) ? ASSIST : MANUAL;

  // The driver's sticks. Normalised to -1 .. +1.
  float stick_fwd  = norm_stick(rc.ch[CH_THROTTLE]);
  float stick_turn = norm_stick(rc.ch[CH_STEER]);
  // The speed dial is a ceiling the driver sets, 0 .. 1.
  float ceiling = norm_dial(rc.ch[CH_SPEED]) * DUTY_MAX;

  // Any real stick input takes priority over the Brain for a short while.
  if (fabsf(stick_fwd) > 0.02f || fabsf(stick_turn) > 0.02f)
    stick_override_until_ms = now + 2000;

  float cmd_fwd, cmd_turn, cmd_ceiling;

  if (mode == ASSIST && now > stick_override_until_ms) {
    // --- Rule 7: in ASSIST, the Brain must be alive -----------------------
    if (!brain.valid) {
      stop_reason = R_NO_BRAIN;
      ramp_to(0.0f, 0.0f);
      return;
    }
    cmd_fwd     = brain.speed;
    cmd_turn    = brain.turn;
    // The Brain never gets the full speed range. Even when it is working.
    cmd_ceiling = fminf(ceiling, DUTY_MAX_ASSIST);
  } else {
    cmd_fwd     = stick_fwd;
    cmd_turn    = stick_turn;
    cmd_ceiling = ceiling;
  }

  // Skid steer mix, then scale by the ceiling.
  want_l = (cmd_fwd + cmd_turn * TURN_GAIN) * cmd_ceiling;
  want_r = (cmd_fwd - cmd_turn * TURN_GAIN) * cmd_ceiling;

  // --- Rule 8: the bumper veto --------------------------------------------
  // It can only REDUCE the command. It can never add to it, and it can never
  // change its sign. That property is what makes it safe to trust.
  float veto = bumper_scale(cmd_fwd);
  if (veto < 1.0f) stop_reason = R_BUMPER;
  want_l *= veto;
  want_r *= veto;

  // --- Rule 9: motor temperature ------------------------------------------
  // Read from each hub motor's own thermistor.
  float heat = fminf(thermal_scale(side_l.temp_c), thermal_scale(side_r.temp_c));
  if (heat < 1.0f) stop_reason = R_MOTOR_HOT;
  want_l *= heat;
  want_r *= heat;

  // --- Rule 11: scale each side by its OWN pack voltage -------------------
  // Applied BEFORE the slew limiter, so what gets ramped is the final target.
  // Aims for the same volts at each motor rather than the same duty fraction,
  // which is what keeps it driving straight as the packs drift apart.
  // docs/01-architecture.md section 3b, trap 1.
  want_l *= PACK_NOMINAL_V / side_l.volts;
  want_r *= PACK_NOMINAL_V / side_r.volts;

  want_l = clampf(want_l, -DUTY_MAX, DUTY_MAX);
  want_r = clampf(want_r, -DUTY_MAX, DUTY_MAX);

  // --- Rule 10: slew limit ------------------------------------------------
  ramp_to(want_l, want_r);
}

// Drop the contactors and forget any ramp. Used only for rules 1 and 2, where
// the motors have no power anyway so there is nothing to ramp down.
void hold_off() {
  digitalWrite(PIN_ARM_OUT, LOW);
  duty_l = 0.0f;
  duty_r = 0.0f;
}

// Move duty_l/duty_r towards the target at no more than the slew rate.
// Every stop in this firmware comes through here, which is why no stop is ever
// a slam. A slam on a 910 mm tall robot could pitch it onto its face.
void ramp_to(float tl, float tr) {
  const float up   = SLEW_UP_PER_S   / LOOP_HZ;
  const float down = SLEW_DOWN_PER_S / LOOP_HZ;
  duty_l = slew1(duty_l, tl, up, down);
  duty_r = slew1(duty_r, tr, up, down);
}

float slew1(float now, float want, float up, float down) {
  // "up" means away from zero, "down" means towards zero. Getting this the
  // wrong way round would make stopping slower than starting.
  bool towards_zero = fabsf(want) < fabsf(now);
  float step = towards_zero ? down : up;
  float d = want - now;
  if (d >  step) d =  step;
  if (d < -step) d = -step;
  return now + d;
}

// ===========================================================================
//  THROTTLE OUTPUT — DAC per side, reverse line per side
// ===========================================================================
// This replaced send_duty()/can_tx(). Three things happen here, in this order,
// and the order matters:
//
//   1. decide the direction, and refuse to change it while the wheel turns;
//   2. write the throttle voltage;
//   3. remember whether the write worked, because wdt_kick() reads that.
//
// The e-brake line is asserted whenever we are stopped for a reason. It is the
// same input the emergency stop is wired into, which is what it is for.
void drive_out(uint32_t now) {
  static uint32_t last = 0;
  if (now - last < 1000 / DAC_TX_HZ) return;
  last = now;

  bool ok = true;
  ok &= side_out(side_l, duty_l, PIN_REV_L, PIN_BRAKE_L, DAC_ADDR_L, now);
  ok &= side_out(side_r, duty_r, PIN_REV_R, PIN_BRAKE_R, DAC_ADDR_R, now);
  output_ok = ok;
}

bool side_out(SideState &s, float duty, uint8_t rev_pin, uint8_t brake_pin,
              uint8_t dac_addr, uint32_t now) {
  float mag = fabsf(duty);
  int8_t want_dir = (duty >  REV_ZERO_DUTY) ?  1
                  : (duty < -REV_ZERO_DUTY) ? -1 : 0;

  // --- the direction interlock --------------------------------------------
  // Scooter controllers commonly refuse to reverse while the wheel is still
  // turning, and some are damaged by being asked. So a direction change is:
  // command zero, wait for the halls to fall silent, then flip the line.
  if (want_dir != 0 && s.dir != 0 && want_dir != s.dir) {
    if (now - s.hall_last_ms < REV_QUIET_MS) {
      mag = 0.0f;                    // still rolling: stop first, flip later
    } else {
      s.dir = want_dir;
      digitalWrite(rev_pin, want_dir < 0 ? HIGH : LOW);
    }
  } else if (want_dir != 0 && s.dir == 0) {
    s.dir = want_dir;
    digitalWrite(rev_pin, want_dir < 0 ? HIGH : LOW);
  }

  // Reverse on these controllers is capped in their own firmware. Asking for
  // more than the cap makes the robot's behaviour depend on an undocumented
  // number, so ask for the cap and no more.
  if (s.dir < 0) mag = fminf(mag, REVERSE_CEILING);

  // The e-brake goes on when we are stopped because something is wrong, not
  // every time the stick is centred — otherwise the robot cannot coast.
  bool braking = (stop_reason != RUNNING) && (mag < REV_ZERO_DUTY);
  digitalWrite(brake_pin, braking ? HIGH : LOW);

  return dac_write(dac_addr, throttle_counts(mag));
}

// Turn a 0..1 magnitude into DAC counts, using the two voltages you measured
// off the real throttle. Below REV_ZERO_DUTY this returns the REST voltage
// exactly, so "stopped" is the same number the controller sees from a thumb
// that let go.
uint16_t throttle_counts(float mag) {
  mag = clampf(mag, 0.0f, 1.0f);
  float v = THROTTLE_REST_V + mag * (THROTTLE_FULL_V - THROTTLE_REST_V);
  float counts = v / DAC_SUPPLY_V * (float)DAC_COUNTS;
  if (counts < 0) counts = 0;
  if (counts > DAC_COUNTS) counts = DAC_COUNTS;
  return (uint16_t)counts;
}

// MCP4725 fast-mode write: two bytes, no EEPROM. Returns false if the device
// did not acknowledge — a pulled wire, a dead DAC, a locked-up I2C bus.
// THE RETURN VALUE IS A SAFETY SIGNAL. Do not ignore it.
bool dac_write(uint8_t addr, uint16_t value) {
  Wire.beginTransmission(addr);
  Wire.write((uint8_t)((value >> 8) & 0x0F));
  Wire.write((uint8_t)(value & 0xFF));
  return Wire.endTransmission() == 0;
}

// ===========================================================================
//  THE HARDWARE WATCHDOG
// ===========================================================================
// Square wave while this firmware is healthy. The moment it stops, a relay
// with normally-closed contacts falls closed and shorts both throttle lines to
// ground. Nothing in software has to work for that to happen.
//
// It is kicked ONLY when the last DAC write succeeded. That is deliberate and
// it is safety log test 16: a Teensy that is alive but has lost the I2C bus
// would otherwise keep kicking happily while the throttle stayed stuck at its
// last value. The blind spot is closed by refusing to kick.
void wdt_kick(uint32_t now) {
  static uint32_t last = 0;
  if (!output_ok) return;                  // <-- the whole point. Do not "fix".
  if (now - last < 5) return;              // 100 Hz square wave
  last = now;
  digitalWrite(PIN_WDT_KICK, !digitalRead(PIN_WDT_KICK));
}

// ===========================================================================
//  THE SENSORS THE CONTROLLERS DO NOT PROVIDE
// ===========================================================================
// Everything here is measured against the single bonded pack negative. If that
// bond is missing these numbers are plausible and wrong, which is worse than
// missing. docs/01-architecture.md section 3b, trap 3.
void sense_poll() {
  sense_side(side_l, PIN_VOLT_L, VOLT_SCALE_L, PIN_TEMP_L, PIN_CURR_L);
  sense_side(side_r, PIN_VOLT_R, VOLT_SCALE_R, PIN_TEMP_R, PIN_CURR_R);
}

void sense_side(SideState &s, uint8_t vpin, float vscale,
                uint8_t tpin, uint8_t cpin) {
  // A light low-pass on all three. Motor phase wires run near these cables and
  // a single noisy sample must never trip a rule on its own.
  const float a = 0.05f;
  float v = (float)analogRead(vpin) / (float)ADC_COUNTS * ADC_REF_V * vscale;
  s.volts = s.volts == 0.0f ? v : s.volts + a * (v - s.volts);
  s.sense_ok = (s.volts > VOLT_ABSENT_V);

  float t = therm_c(tpin);
  s.temp_c = s.temp_c == 0.0f ? t : s.temp_c + a * (t - s.temp_c);

  float pin_v = (float)analogRead(cpin) / (float)ADC_COUNTS * ADC_REF_V;
  float sensor_v = pin_v * ACS_DIV_RATIO;
  float amps = (sensor_v - ACS_ZERO_V) * 1000.0f / ACS_MV_PER_A;
  s.amps = s.amps + a * (amps - s.amps);
}
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

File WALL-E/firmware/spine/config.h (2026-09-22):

// config.h — every number you might want to change, in one place.
//
// Rule for this file: if a value needs tuning in the field, it belongs here.
// If changing it could make the robot less safe, it gets a comment saying so.
//
// See WALL-E/docs/01-architecture.md section 3 for the rules these serve.
//
// ---------------------------------------------------------------------------
//  REWRITTEN 2026-09-22 FOR DECISION D7
// ---------------------------------------------------------------------------
//  There is no data bus to the motors. They are driven by the two
//  scooter controllers already owned, through a DAC per side that makes the
//  throttle voltage. Everything they do not report is now a sensor this
//  board reads itself:
//
//    what it is                 how this board gets it
//    -------------------------  ------------------------------------------
//    duty command               MCP4725 DAC -> throttle wire, + reverse opto
//    input voltage  (rules 5,11) resistor divider per pack, analogue in
//    motor temperature (rule 9) the hub motor's own thermistor, analogue in
//    "is the track turning?" (4) counting the motor's hall edges
//    motor current              ACS758 per pack, telemetry only
//    command timeout            THE HARDWARE WATCHDOG. See PIN_WDT_KICK.
//
//  docs/05-bom.md section 1b is the parts list this file assumes.

#pragma once

// ===========================================================================
//  TIMING
// ===========================================================================
// The control loop rate. 1 kHz is the promise the whole safety argument rests
// on: no single decision is ever more than 1 ms stale.
const uint32_t LOOP_HZ          = 1000;
const uint32_t LOOP_US          = 1000000UL / LOOP_HZ;

// How long we tolerate silence before deciding a source is dead.
const uint32_t RC_TIMEOUT_MS    = 100;   // radio. Do not raise this.
const uint32_t BRAIN_TIMEOUT_MS = 100;   // Jetson heartbeat

// FS-i6X + FS-iA6B: the receiver is reported to keep emitting iBus frames
// containing the LAST STICK VALUES after the transmitter is switched off,
// instead of applying its failsafe. A frame-arrival test cannot see that: the
// frames keep arriving, on time, and the robot keeps driving.
//
// So a frame whose 14 channels are bit-identical to the previous frame for
// this long is treated as a dead link. A live link jitters by at least one
// count on some channel; a frozen one repeats exactly.
//
// Verify on blocks: drive, switch the transmitter off, confirm the tracks stop.
// Safety log test 3.
const uint32_t RC_FROZEN_MS     = 500;

// After the Brain comes back, ignore it for this long. Stops a Jetson that is
// crash-looping from producing repeated bursts of movement.
const uint32_t BRAIN_REARM_MS   = 1000;

// ===========================================================================
//  PINS  (Teensy 4.0)
// ===========================================================================
// Pins 0 and 1 are Serial1 (the radio). 18 and 19 are I2C to the DACs and the
// ToF multiplexer. Do not reuse any of those.
const uint8_t PIN_ARM_OUT   = 2;   // MOSFET holding the contactor coils in.
                                   //   LOW = contactors drop = motors dead.
const uint8_t PIN_ESTOP_SNS = 3;   // senses the E-stop chain. Input, active LOW
const uint8_t PIN_TOF_RESET = 4;   // hard reset line for the ToF ring
const uint8_t PIN_LED_OK    = 13;  // on-board LED, heartbeat blink

// --- THE HARDWARE WATCHDOG -------------------------------------------------
// This pin is the most important output on the board. It is squarewaved while,
// and only while, this firmware believes it is in control. A TLC555/TPS3823
// holds a normally-closed relay OPEN as long as the pulses keep coming. Stop
// them — crash, hang, reset, failed DAC write — and the relay falls closed and
// SHORTS BOTH THROTTLE LINES TO GROUND.
//
// A scooter controller has no command timeout of its own, and the DAC holds
// its last value forever, so this relay is the ENTIRE replacement for the
// behaviour no scooter controller provides. docs/01-architecture.md section 4.
const uint8_t PIN_WDT_KICK  = 5;

// --- the two opto-isolated lines per controller ----------------------------
// A scooter controller cannot be told to go backwards with a voltage: the
// throttle is unipolar. Direction is a separate wire, pulled to ground.
const uint8_t PIN_REV_L     = 6;   // reverse line, left controller
const uint8_t PIN_REV_R     = 7;   // reverse line, right controller
const uint8_t PIN_BRAKE_L   = 8;   // e-brake line, left controller
const uint8_t PIN_BRAKE_R   = 9;   // e-brake line, right controller

// --- hall edges, one wire tapped from each motor's hall cable (rule 4) -----
const uint8_t PIN_HALL_L    = 10;
const uint8_t PIN_HALL_R    = 11;
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

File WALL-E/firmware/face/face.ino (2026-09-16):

// face.ino — the Face. ESP32-S3, one board per eye.
//
// This board owns the animation. The Brain sends intent a few times a second
// ("look 20 degrees left", "you are curious now") and this board turns that
// into smooth 30 fps movement, blinks, saccades and servo motion.
//
// The split matters for a practical reason as much as an architectural one:
// you can develop and test the whole head with the Jetson unplugged, by typing
// commands into a serial terminal.
//
// This board CANNOT move the robot. It has no connection to the Spine, the CAN
// bus or the contactors. That is deliberate.
//
// Board: ESP32-S3. Libraries: LovyanGFX (display), ESP32Servo (servos).

#include <LovyanGFX.hpp>
#include "config.h"

// ---------------------------------------------------------------------------
//  DISPLAY
// ---------------------------------------------------------------------------
// The 480x480 round panel is QSPI, which LovyanGFX supports but needs a panel
// config block filled in from the module's datasheet. That block is vendor
// specific, so it lives in its own header rather than cluttering this file.
//
// TODO: fill in panel_cfg.h from the Waveshare 2.1in round LCD documentation.
// Until then, everything below runs against the sprite and simply draws to
// nothing, which is still enough to test the animation logic over serial.
#include "panel_cfg.h"
static LGFX lcd;
static LGFX_Sprite eye(&lcd);       // draw off-screen, push once. No tearing.

// ---------------------------------------------------------------------------
//  STATE
// ---------------------------------------------------------------------------
enum Mood : uint8_t { IDLE = 0, CURIOUS, HAPPY, SAD, ALARM, SLEEPY, MOOD_N };
const char* const MOOD_NAME[MOOD_N] =
  {"idle", "curious", "happy", "sad", "alarm", "sleepy"};

struct {
  // where the Brain wants us to look, -1..+1 in each axis
  float want_x = 0, want_y = 0;
  // where we actually are, smoothed
  float x = 0, y = 0;
  // saccade offset, added on top
  float sx = 0, sy = 0;
  Mood  mood = IDLE;
  float lid = 0;            // 0 = open, 1 = shut
  float lid_want = 0;
  float tilt_deg = 0, tilt_want = 0;
  float pan_deg = 0,  pan_want = 0;
  uint32_t brain_last_ms = 0;
} st;

bool is_left = true;        // set in setup() from the select pin

// ===========================================================================
//  SETUP
// ===========================================================================
void setup() {
  pinMode(PIN_EYE_SELECT, INPUT_PULLUP);
  is_left = (digitalRead(PIN_EYE_SELECT) == LOW);

  // The left board drives the sync line, the right board listens to it.
  pinMode(PIN_SYNC, is_left ? OUTPUT : INPUT);

  Serial.begin(BRAIN_BAUD);

  lcd.init();
  lcd.setRotation(0);
  lcd.fillScreen(COL_BG);
  eye.setColorDepth(16);
  eye.createSprite(SCR_W, SCR_H);

  servo_begin();
  randomSeed(esp_random());
}

// ===========================================================================
//  MAIN LOOP
// ===========================================================================
void loop() {
  static uint32_t next_ms = 0;
  const uint32_t frame_ms = 1000 / TARGET_FPS;

  brain_poll();

  uint32_t now = millis();
  if ((int32_t)(now - next_ms) < 0) return;
  next_ms = now + frame_ms;

  frame_sync();
  idle_behaviour(now);
  blink_update(now);
  saccade_update(now);
  gaze_update();
  mood_apply();
  servo_update();
  draw();
}

// Keep the two eyes on the same frame. The left board pulses, the right board
// waits for the edge. If the wire is broken or the other board is dead, the
// wait times out immediately and each eye just runs on its own clock.
void frame_sync() {
  if (is_left) {
    digitalWrite(PIN_SYNC, HIGH);
    delayMicroseconds(50);
    digitalWrite(PIN_SYNC, LOW);
  } else {
    uint32_t t0 = micros();
    while (digitalRead(PIN_SYNC) == LOW) {
      if (micros() - t0 > 2000) break;     // no partner, carry on alone
    }
  }
}

// ===========================================================================
//  BEHAVIOUR WHEN THE BRAIN IS QUIET
// ===========================================================================
// A crashed Jetson must leave a robot that looks bored, not one that looks
// broken. Frozen eyes read as "switched off" to everyone watching.
void idle_behaviour(uint32_t now) {
  if (now - st.brain_last_ms < BRAIN_IDLE_MS) return;

  st.mood = IDLE;
  // Drift slowly around, looking at nothing in particular.
  static uint32_t next_look = 0;
  if (now > next_look) {
    next_look = now + 1800 + random(2600);
    st.want_x = (random(200) - 100) / 140.0f;
    st.want_y = (random(200) - 100) / 220.0f;
  }
}
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

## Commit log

2026-07-12 Apollo track pod — Rev 001b: measured datums, track-length solver, belt-clearance fix
    - Real dimensions: track 1083x118 (60mm pitch, 18 links), sprocket OD 180,
    idler OD 108 x 58 on 6302-2RS bearings (15mm axle)
    - Idler spacing A solved from track length by bisecting the belt path
    - Belt-clearance fix: keel standoff relocated between sprocket and pivot,
    pivot raised (drop 20->30), carrier tongue slimmed; PASS/WARN clearance
    guard echoes on every render
    [apollo_track_pod.scad]
2026-07-12 Rev 002: hub-motor fork-mount redesign, exact measured dimensions throughout
    - Sprocket counted 10T -> belt solver corrected to cord line (Ø191): A = 222.2, C = 117.4
    - Carriers redesigned as fork-hung torque-arm plates (Ø10 flatted axle slot + M8 per leg);
    6205 bearings, axle sleeve, anti-rotation link deleted; shocks moved inboard
    - Carriers ride outside belt width - tongue-hits-track failure mode now impossible
    - Blueprint + README filled with exact values (axle lengths, shock eye coords, slot dims,
    385 lb/in spring example); PDF regenerated from Rev 002 HTML
    - Fit risk flagged: 118 belt in 120 front fork gap (1mm/side)
    [apollo_track_pod.scad]
2026-07-15 Rev 002a-002c: shopping guide, per-component build chapters, 3D tensioner, measured fork legs
    - 002a (docs): §7 expanded into a full shopping guide (§7.1-7.9: specs,
    sources, search terms, substitutes, costs, receiving inspection with
    rendered images per BOM row); §9 expanded into per-component build
    chapters (§9.1-9.8: tools, steps, checks, common mistakes); print CSS
    so the PDF paginates one topic per page.
    - 002b: Sheet-6 belt tensioner detailed + modeled explicitly in 3D
    (adjuster blocks on the axle ends, M8 draw bolts through welded lugs,
    jam nuts). Fit-check moved the lug off the plate tip - a tip lug puts
    the bolt head through the belt at slack. New tension_pos param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
    [apollo_track_pod.scad]
2026-07-20 Rev 003/003a: M16 pivot, 140mm fork gaps, full 3D collision audit
    Rev 003 (owner changes):
    - Pivot axle M20 -> M16 cl.10.9; bushings SAE 841 flanged 16x22x20,
    boss tubes 32x22, spacer 22x16, thrust washers 30x16, seats ream 22 H7
    - Fork gaps re-measured 140mm front AND rear (was 120/140): pods now
    identical (M16x190 x2, keel 148/172 x2, shocks |z|=94); the 1mm/side
    front belt-fit risk is retired (11mm/side)
    Rev 003a (collision audit, all guarded with PASS/WARN echoes):
    - Pivot stack made continuous: bosses point in (trailing) / out (leading),
    centre spacer ~60 -> ~14, new outboard sleeves ~7 x2, washers 4 -> 6
    - Shock through-bolt moved 0.68C -> 0.485C (was inside the idler wheel);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
    [apollo_track_pod.scad]
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2026-07-23 Rev 004c: confirm real pivot bolt (M16x195, 45mm thread) and 31 OD boss tube
    Owner-sourced hardware replaces the earlier design placeholders:
    - Pivot bolt is a real headed M16x195, threaded 45mm on one end only (not
    a double-end stud). Verified: smooth shank 195-45=150 clears the
    farthest bushing edge (145.85 from head) with 4mm margin, which falls
    inside the outboard-sleeve zone rather than on a bearing surface; nut
    fully engages 16mm proud within the threaded zone. Needs only ONE M16
    nylock per bolt -- corrects earlier shopping-list drafts that assumed a
    stud (nut each end, 4 total); now 2 nylocks total (1/pod).
    - Boss tube sourced at 31 OD x 22 ID (was 32 OD spec) -- wall thi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
    [apollo_track_pod.scad]
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2026-07-25 Rev 005c: printed 11T sprocket matched to the measured belt + hub
    - Belt measured (Yonggu): pyramid-pair lugs astride centreline, 22 gap,
    15 tall w/ vertical inner face, base 25, pitch 60 confirmed; hub rim
    Ø165 x 35 w, tunnel 20.5 x 8 deep. Idlers ride lug tips (no F=62 channel).
    - Sprocket: rib 18x16.54 + 11 T-teeth 51x20, blades to Ø168; face Ø198,
    cord Ø210; tooth marks 56.6 on the rib top (32.7 deg).
    - Suspension re-tuned for solved A=160.2: drop 38->55, a=0.38C (MR 0.438),
    cross-brace 17..41, keel below the arm bar; 16/16 guards PASS.
    - README + blueprint revision slip + PDF synced.
    [apollo_track_pod.scad]
2026-07-25 Rev 010 FINAL: cut-rim 10T sprocket pair (010 cut / 009 no-cut twin)
    The two-day belt-reality arc, concluded by owner measurements:
    - Hub fins (5x 4.1mm blades, 72 deg) arch to the tunnel floor's UNDERSIDE:
    flange cut is clean; 9T excluded (lugs would dive O130 into the arches);
    10T final: rib 18x15 on the O149x20.5 floor, wheel O179, cord O191,
    marks 56.2 @ 36 deg. Interim fin-drive-key concept built and removed.
    - Rev 009 no-cut twin finalized: 11T on factory rim, KEEL DELETED
    (use_keel switch; fork legs box the carriers since Rev 002), carriers
    unified at 224 in both revisions (parametric bottom past keel — fixes
    owner-caught floating-keel bug).
    - Idler axles: M12 GB901 8.8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
    [apollo_track_pod.scad, apollo_track_pod_rev009_uncut.scad]
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2026-07-28 Print-ready wheel-hub sprocket (rev 009 + 010): STLs, per-rev blueprints; Rev 010c keel deletion
    - sprocket_print.scad: new companion model that turns the rev 009 (11T,
    uncut Ø165 rim) and rev 010 (10T, cut Ø149 floor) sprocket geometry into
    an actually printable part: clamp shell / well fill, two bolt-together
    half-shells split through tooth gaps, under-floor bolt ring on the
    non-fin side (NEW design vs the assembly model), 2-tooth test arc,
    clearance guard echoes (ring vs lug-tip sweep, ring vs Ø123 casing).
    - stl/: rendered half_A / half_B / test_arc for both revs (manifold, guards PASS).
    - wheel_hub_print_blueprint_rev009/rev010 (.html + .pdf): per-rev sheets
    with dimensio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
    [apollo_track_pod.scad, rev009_half_A.stl, rev009_half_B.stl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]
2026-07-28 Consolidate repo per revision: rev009/rev010 folders are the only workspaces
    - Root reduced to an index README; all working files moved into
    archive/rev009-uncut-11T/ and archive/rev010-cut-rim-10T-final/
    (scad, sprocket_print.scad, STLs, wheel blueprints, plates PDF/DXF,
    pod blueprint HTML+PDF).
    - Plates PDF updated: cross-brace webs corrected to 2x ~51 (trailing)
    + 2x ~66.5 (leading) — fork widths differ, owner-caught.
    - Standing rule: every future change lands in the two rev folders only.
    [apollo_track_pod.scad, plates_rev010.dxf, rev009_half_A.stl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]
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2026-08-23 Rev 011b: belt tensioner flipped to a pusher — the draw-bolt head hit the belt teeth
    Owner found the pull-type draw-bolt head touching the track's drive
    lugs: the head sat ~44 mm behind the axle, dead centre of the belt
    wrap, where the lug TIPS sweep only D/2 - lug_h = 39 mm. The old
    guard checked the belt face (10 mm clear) and missed the teeth.
    No rear-mounted head can clear them; the forward side of the idler
    is never wrapped (wrap runs ~52deg over the rear to the bottom), so:
    - pusher block 26x14x6 welded FORWARD of the slot (rear face at
    C-15), M6 tapped or welded-nut; screwing IN pushes the axle
    rearward — bolt in compression, positioner only, the torqued
    M12 nylocks still h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
    [apollo_track_pod_rev011.scad]
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2026-08-29 Rev 011d merged: bracket blade and shock tab become one plate per side
    Owner: no reason for two plates — the blade already crosses the axle,
    so it continues to the shock eye and the rear pod's separate stubs
    are deleted. Two DISTINCT plates now (no longer a flip pair, mark L/R):
    - TRAILING side: 262 x 40 x 6 — key at 190 from the front end, Ø8.4
    shock eye at 242 (= +52.06/+2.44 of the axle), 20 end margin
    - LEADING side: 210 x 40 x 6 — key at 190, eye at 138 (= -52.06);
    the eye fell inside the existing blade, no extension needed
    - axle stack simplifies to carrier + plate (two keyed plates, was
    three); shock load path runs straight down the plate into the
    fork bolts instead of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
    [apollo_track_pod_rev011.scad]
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2026-08-29 Rev 011d: bolt pad from the 40 bar — stepped strips, and a belt-clearance echo
    Owner has only 40-wide stock, so the 65x55 pad is gone: the pad is a
    plain 65x40x6 strip one layer inboard, shifted 15 up the leg (covers
    15..55) while the blade covers 0..40 — 25 of overlap carrying two
    65-long fillets. Upper M10 row (41 up) lives in the pad, lower row
    (14 up) in the blade; both rows grip leg 4 + packing 11 + one 6
    plate = 21, so all four bolts are identical M10x45.
    Also: new echo 'belt edge (59) to pad plane (74): 15 mm' — in the 3D
    view the pad passes in front of the belt and looks like contact;
    it is 15 mm outboard. Template pad block redrawn (65x40, upper row
    at 26 up the strip), stack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
    [apollo_track_pod_rev011.scad]
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2026-08-29 Rev 011d: delete the bolt pad — owner caught two real faults in the render
    The stepped-pad scheme was broken and the bracket view exposed it:
    (1) a 6 mm VOID at the pad layer under the lower bolt row — torquing
    would bend the blade into the gap; (2) the upper row sat 1 mm above
    the blade's top edge, so the bolt shanks collided with the blade.
    Fix: no pad at all. Both M10 rows move INSIDE the blade band —
    2x2 pattern 35 x 14, columns 15/50 from the front end, rows 13/27
    up the leg (y -7/+7 of the axle line). Every bolt runs the same
    honest stack: leg 4 + packing 11 + blade 6 = 21. Edge distances
    13 everywhere (1.25d). The 35 span carries the in-plane moment;
    the mandatory perimeter wel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
    [apollo_track_pod_rev011.scad]
2026-08-30 Rev 011d: packing back to 17 — the pad's 6 mm never got refilled
    Owner question about layer order flushed out a leftover: when the
    pad was deleted, brk_pack stayed 11 — but the pad had been filling
    6 of the gap. The blade plane is FIXED at 80 by the carrier (shared
    keyed axle); leg outer face is 62.85; the packing must fill 17.15.
    With 11 the blade would bend 6 mm between fork and axle.
    Corrected stack: backing strip 6 / leg 4 / packing 17 (6+6+5, cut
    to measured gap) / blade 6 = grip 33 -> M10 x 55 cl.8.8. Template
    and bracket-view bolts updated. Guards PASS, zero warnings.
    Layer-order answer recorded in the params: blade+packing sit OUTBOARD
    of the leg because the carrier dictates th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
    [apollo_track_pod_rev011.scad]
2026-08-30 Rev 011d: 2x M8 blade-to-carrier bolts beside the axle key
    Owner request: a second, spread-out anti-rotation path between blade
    and carrier next to the keyed axle, welded on top at final fit
    (pod-side weld — removability at the fork is untouched).
    - 2 x Ø8.4 in both plates, on the carrier centreline, 12 above and
    12 below the axle (clears the key by ~3, 24 spread)
    - bolts: M8 x 30 — exactly the rear pod's freed carrier-to-leg
    bolts, reused; blade 6 + carrier 6 + washer + nylock
    - holes added in carrier_2d (gated on use_bracket — front pod skips
    drilling), both blade renders, plates layout, 1:1 template
    (+ CARRIER JOINT note), bracket view draws the bolts + flag
    - stale labels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
    [apollo_track_pod_rev011.scad]
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2026-09-10 Rev 012 draft: render_mode="chassis" — the scratch-built floor
    The donor deck is scrapped (two packs won't fit a one-pack battery box).
    What survives is the front end only: head tube + fork + front hub motor,
    i.e. the front pod exactly as Rev 011 draws it. The rear pod hangs from
    legs welded to the new floor, which makes the Rev 011d bracket obsolete.
    New mode draws the whole vehicle in vehicle coordinates: donor front end
    as a ghost, two rails + cross members + skin, both pods, battery bay,
    rider footprint. Every chassis number is a PLACEHOLDER and says so.
    Three values are DERIVED, not chosen:
    - plate_ang / plate_b — face A lies flat on the deck and face B lands
    on the neck, so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
    [apollo_track_pod_rev011.scad]
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2026-09-10 Rev 012: delete the rear bracket, cut pod wells — owner caught two faults
    Owner, 2026-09-10: "why is the chassis not connected straight to the hub
    wheel? why do we need the green plate at all?" Right on both counts.
    The green plate is the Rev 011d bracket blade. Its only job was hanging the
    pod off a donor rear fork whose inner gap measured 117.7 against a 118 belt.
    We were working around a fork we are now cutting off and throwing away. Gone
    with it: the keyed blade, 17 packing, the 8x M10 friction joint and its
    1h/5h/20h retorque, the backing strips, the 55 mm rearward wheel shift.
    Replacement is short. The carrier already sits at |z|=74..80 and spans
    y=64..284, so it passes the rail on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
    [apollo_track_pod_rev011.scad]
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2026-09-10 Rev 012c: tabs go THROUGH the rear cross tube; green plate uncut, above the spring
    Owner asked whether two small tabs welded to the rectangle tube are enough.
    The welds are; the 2 mm tube wall is not. A tab welded only ON the face
    loads the wall like a can lid: yield-line estimate ~93 N·m per tab against
    ~252 N·m needed (the old guard checked the weld throat, never the wall).
    Fix: gp_tab_through — each tab passes through slots in BOTH walls and is
    welded on both faces, so the moment reaches the walls as in-plane shear:
    wall 56 MPa, welds 14 MPa, PASS. Tabs 105 -> 148 (43 inside the tube),
    8 slots 61 x 6.5 in the rear cross tube, 60x6 total 1308 -> 1480 mm,
    steel 11.5 -> 11.9 kg. New modu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
    [apollo_track_pod_rev011.scad, rev012_plates.dxf]
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2026-09-14 Rev 012: battery bay set to 1000 mm clear
    The bay was derived from the two packs alone (840 mm), which left no room for
    the controller and wiring. The bay is now its own parameter, bay_len_set = 1000,
    floored at what the packs need (bay_pack_len), so it can never be cut shorter
    than the batteries. The 160 mm of spare length sits behind the rear pack.
    Cascade: wheelbase 1320 -> 1480, rails 1027 -> 1187, lid and tray 920 -> 1080,
    chassis 16.2 -> 18.2 kg. A new guard echoes the spare bay length. All chassis
    guards still PASS; the only WARNs are the lower shock bolt bending inherited
    from Rev 011.
    The green plates, plates.dxf and the 1:1 template PDFs are byte-identical -
    the rear pod joint do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
    [apollo_track_pod_rev012.scad]
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2026-09-16 WALL-E: side-by-side frame model, all guards pass
    The frame that holds the two built pods left and right. Parametric, in the same
    style as the pod model: every number derived, 18 clearance and stress guards,
    cut list and mass estimate echoed on every run.
    Layout: pods 500 mm apart centre to centre, so 700 mm overall width. Rails are
    60x30x3 box whose outer faces lie flat on the inboard green plates, exactly the
    Rev 012 joint but mirrored inboard. It reuses the four M12 holes already drilled
    in the plates, so no new holes go into finished pods, and each pod still comes
    off with two bolts per side.
    Both battery packs sit low between the rails, one per pod, matching the split
    power decision.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
    [walle_frame.scad]
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2026-09-16 WALL-E: power and wiring doc, and the bill of materials
    Two problems came out of putting real part numbers against the design.
    The audio amplifier cannot run off the pack. A TPA3255 is rated to 53.5 V
    absolute maximum, and a "48 V" pack is 54.6 V fully charged if it is 13S
    Li-ion, or 58.4 V if it is 16S LiFePO4. It would have worked for weeks and then
    died on the first drive after a full charge. The amplifier now gets its own
    48 to 32 V buck converter, which also keeps the audio current spikes off the
    rail the Jetson sits on.
    The 48 to 12 V isolated converter is far bigger than the placeholder. A real
    100 W part (Mean Well SD-100C-12) is 159 x 97 x 38, not the 110 x 60 x 30 I
    guessed. The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
    [walle_frame.scad]
2026-09-16 WALL-E: firmware for the Spine and the Face, and the Brain skeleton
    Three programs, one per board, with the safety argument from
    docs/01-architecture.md written into the code rather than only described.
    Spine (Teensy 4.1, no operating system). One loop at 1 kHz. arbitrate() walks
    the twelve rules in the same order as the document, with the rule numbers in
    the comments so the two can be checked against each other. Every exit path
    goes through the slew limiter, so no stop is ever a slam — a slam on a 910 mm
    tall robot could pitch it onto its face.
    Three places where it fails in the safe direction rather than the convenient
    one: a bumper ring with no working sensor halves the speed instead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
    [config.h, face.ino, face_link.py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]
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2026-09-16 WALL-E: make the battery box an actually closed box
    Sand was the reason behind the question about moving the packs into the body,
    and it found a real fault. The box was a three-sided plywood U: a floor and two
    side walls that stopped at the rail top, 15 mm BELOW the tops of the packs. It
    was open across the whole top, open at both ends, and it carried four 30 mm
    spanner holes in the sides. It hangs directly inboard of the belts, and the
    belts throw sand inward and upward. It would have filled in a day.
    It is now a closed box. Two end walls, which are the parts that were missing
    entirely, and a gasketed lid. The side walls grew from 107 to 142 mm so they
    reach above the packs and the lid has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
    [walle_frame.scad]
2026-09-16 WALL-E: two 6.5 inch speakers in the chest, and the chest panel they mount to
    Adding the speakers turned up a bug first. The chest recess is 20 mm deep into
    a 12 mm wall, so it cut the front wall clean away and left a hole: you could
    see the electronics through WALL-E's chest. A recessed panel has to BE a panel,
    so there is now a real 12 mm plate set back 20 mm from the front face, and that
    plate is the speaker baffle.
    The drivers are Ø165 cutout, Ø190 rim, 50 mm deep, carried over from the
    scooter build where they were measured. Their position is derived rather than
    chosen: each enclosure has to clear the tallest shelf box by 20 mm and stay
    under the body lid, and the driver then centres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
    [walle_frame.scad]
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2026-09-16 WALL-E: give view a Customizer dropdown, add the missing chest mode
    walle.scad's "view" had a prose comment instead of the // [a, b, c]
    annotation OpenSCAD needs, so the Customizer showed a text box and you had to
    know the mode names to type them. It now lists all eleven views with readable
    labels.
    cad/walle_frame.scad's render_mode list was missing "chest", which was added
    when the speakers went in. The mode worked; it just was not offered.
    [apollo_track_pod_rev012.scad, walle.scad, walle_frame.scad]
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2026-09-16 WALL-E: plywood body and wooden eyes; fix pod width error
    Owner decisions 2026-09-17: the steel is already owned, so the frame stays
    steel. Only the body and the eyes change to plywood.
    Body is now 12 mm solid plywood instead of a foam core with a thin ply skin
    and fibreglass. Its mass is computed from its own geometry rather than being
    a 25 kg guess, which turned out to be the single biggest improvement in the
    project so far:
    whole robot 100.4 -> 88.9 kg
    centre of mass 349 -> 334 mm
    tips forward at 17.7 -> 18.4 deg
    ground pressure 0.184 -> 0.163 kg/cm2
    body cost 760 -> 315 dollars
    body_com_frac was a flat 0.40, justified by "the upper walls are foam". They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
    [pod_interface.scad, walle_frame.scad]
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2026-09-18 WALL-E: remove the shock bolt retrofit, and fix the stale 168 mm pod geometry
    Owner reports the lower shock bolt is fixed on the real pods, so 02-shock-bolt.md
    is deleted along with decision D2, risk R3, the 50 dollar BOM line, the phase
    tasks and the budget row. Recorded as locked decision L24 so the gap in the D
    numbering has an explanation, and the analysis stays in git history.
    While removing it I found the same stale pod geometry that pod_interface.scad
    was corrected for on 2026-09-17, still live in five places: 00-plan.md called
    the carrier spacing 168 mm and the shocks inboard at |z|=73, locked decision L8
    fixed the frame mounting width at 168 mm, README.md repeated it, and the
    walle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
    [walle_frame.scad]
2026-09-18 rev013: the pivot shim is a measured 19 mm, not the 20 first written
    Owner measured the sleeve on the M16 pivot axle inboard of each carrier plate
    at 19 mm. Carrier inner face moves 94 -> 93 and the outboard pivot sleeve is
    11.25 + 19 = 30.25. Still well past the 9 mm flip point, so the shocks stay
    inboard and every lower shock guard still passes.
    [apollo_track_pod_rev013.scad]
2026-09-18 rev013: measured eye tube and coil, double shear switched off for review
    Owner measurements 2026-09-18: the shock lower eye tube is 24 mm long, not the
    10 mm guess, and the spring coil is 45 across, not 44.
    The coil diameter was hard-coded as 44, or as a bare radius 22, in three
    separate guards and two label strings, none linked to each other. It is now one
    parameter, coil_d, that all of them read. The carrier strip clearance moves from
    9.72 to 9.22 mm as a result.
    ds_strap is false at the owner's request so the mount can be reviewed without
    the outer strap. THIS LEAVES THE LOWER SHOCK BOLT OVER YIELD: 384 MPa on the
    trailing arm and 311 on the leading, against a 235 MPa limit, both report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
    [apollo_track_pod_rev013.scad]
2026-09-18 rev013: take the carrier position from the tape, and put the green plates inboard
    Two owner corrections, and a change in how this file treats a built pod.
    The green plates are INBOARD of the carriers, not outboard. The carrier is the
    outermost steel on each side. gp_z0 read cz + carrier_t, which put the plate on
    the wrong face and made the pod 12 mm wider per side than it is. The rail that
    lands on that plate moves with it.
    cz is now MEASURED, not calculated. Owner read 165 mm clear between the carrier
    inner faces, so cz = 82.5. Every attempt to derive it from fork_gap + leg_t +
    shim has been wrong, because the chain depends on which fork the pod has. The
    old chain is kept as cz_calc and c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
    [apollo_track_pod_rev013.scad]
2026-09-18 rev013: owner's own fork bolts to the carrier, so the width stack inverts
    Owner is building his own fork and it attaches to the carrier plate's OUTER
    face. Up to Rev 012 it was the other way round - the carrier bolted to the fork
    leg's outer face, so cz was derived from fork_gap. The carriers are the
    reference now and the fork follows them:
    fork_gap = 2 x (cz + carrier_t) = 2 x (82.5 + 6) = 177
    which is the owner's own figure, 165 clear plus two 6 mm plates. The donor fork
    and the Rev 011d blade conversion are both dropped.
    carrier_shim is retired to 0. It no longer sets the carrier position, and with
    the fork on the outside there is no fork-to-carrier shim in the stack at all.
    The 19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
    [apollo_track_pod_rev013.scad]
2026-09-18 rev013: stubs go inboard, and the drawn shock finally reads the measurements
    Owner looked at the assembly render and reported two things wrong.
    The green plates were still outboard. Three separate places set the stub and
    bracket plane to cz + carrier_t, which is now exactly where the owner's new
    fork bolts on. The stub plane is defined once as tab_z0 = cz - stub_t = 76.5,
    against the carrier's INNER face, and the shock hangs off the stub's inner face
    in turn. The Rev 011d bracket is switched off entirely: it existed only to work
    around the donor rear fork, which is no longer part of the build.
    The shock eye did not look 24 mm because the drawn shock was never connected to
    any measurement.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
    [apollo_track_pod_rev013.scad]
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
